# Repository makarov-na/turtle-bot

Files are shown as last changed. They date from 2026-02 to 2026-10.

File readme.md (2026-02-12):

## Реализация по мотивам проекта [TurtleBot3 Burger](https://www.turtlebot.com/) 

### Project goal: bot implementation on commodity hardware

The project uses widely available and cheaper components. 
Created custom waffle 3D models for printing at home with the ability to adapt to various 
components. Source files in FreeCAD format are available.

### Цель проекта: реализация бота с использованием более доступного железа

В проекте используются широко доступные и более дешевые компоненты. 
Реализованы модели для 3D печати в домашних условиях с возможностью адаптации 
под различные компоненты. Для всех деталей доступны исходники в 
формате FreeCAD.

[Ход проекта на YouTube](https://www.youtube.com/playlist?list=PLKxQTQ3TZlLEd_6ZOf-SUxFQ7dUuGvq06)




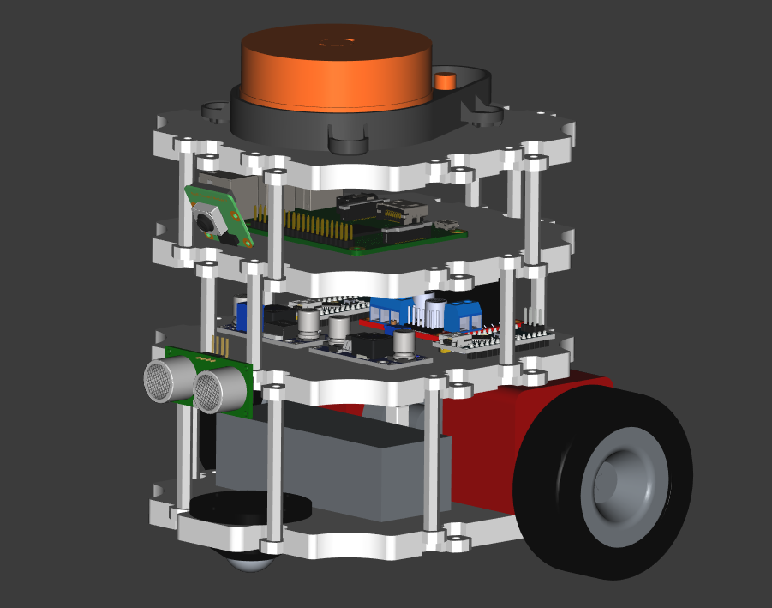
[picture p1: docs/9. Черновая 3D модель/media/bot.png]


1. [Компонентная архитектура](docs/1.%20%D0%9A%D0%BE%D0%BC%D0%BF%D0%BE%D0%BD%D0%B5%D0%BD%D1%82%D0%BD%D0%B0%D1%8F%20%D0%B0%D1%80%D1%85%D0%B8%D1%82%D0%B5%D0%BA%D1%82%D1%83%D1%80%D0%B0/%D0%9A%D0%BE%D0%BC%D0%BF%D0%BE%D0%BD%D0%B5%D0%BD%D1%82%D0%BD%D0%B0%D1%8F%20%D0%B0%D1%80%D1%85%D0%B8%D1%82%D0%B5%D0%BA%D1%82%D1%83%D1%80%D0%B0.md)
1. [Шасси](docs/2.%20%D0%A8%D0%B0%D1%81%D1%81%D0%B8/%D0%A8%D0%B0%D1%81%D1%81%D0%B8.md)
1. [Схема питания](docs/3.%20%D0%A1%D1%85%D0%B5%D0%BC%D0%B0%20%D0%BF%D0%B8%D1%82%D0%B0%D0%BD%D0%B8%D1%8F/%D0%A1%D1%85%D0%B5%D0%BC%D0%B0%20%D0%BF%D0%B8%D1%82%D0%B0%D0%BD%D0%B8%D1%8F.md)
1. [Черновая 3D модель](docs/9.%20%D0%A7%D0%B5%D1%80%D0%BD%D0%BE%D0%B2%D0%B0%D1%8F%203D%20%D0%BC%D0%BE%D0%B4%D0%B5%D0%BB%D1%8C/%D0%A7%D0%B5%D1%80%D0%BD%D0%BE%D0%B2%D0%B0%D1%8F%203D%20%D0%BC%D0%BE%D0%B4%D0%B5%D0%BB%D1%8C.md)
1. [Список компонентов](docs/%D0%A1%D0%BF%D0%B8%D1%81%D0%BE%D0%BA%20%D0%BA%D0%BE%D0%BC%D0%BF%D0%BE%D0%BD%D0%B5%D0%BD%D1%82%D0%BE%D0%B2/%D0%A1%D0%BF%D0%B8%D1%81%D0%BE%D0%BA%20%D0%BA%D0%BE%D0%BC%D0%BF%D0%BE%D0%BD%D0%B5%D0%BD%D1%82%D0%BE%D0%B2.md)
1. [3D модели (FreeCAD)](https://github.com/makarov-na/turtle-bot-3d-models)



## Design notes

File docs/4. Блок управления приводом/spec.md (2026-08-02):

# Описание доработки

## Функции модуля моторов:

* Отключение моторов
* Остановка моторов (силовое торможение)
* Установить линейную скорость в точке середины оси колёс
* Установить угловую скорость в точке середины оси колёс

## Настройки:

* Диаметр колёс, мм
* Колёсная база, мм
* Максимальная скорость, мм/с 

# Техничские детали:

## Программа:

* Нужно сделать скетч для ардуино.
* Функции реализовать в методах stop, power_stop, set_speed(linear_speed, angular_speed)
* Для проверки в главном цикле сделать вызов set_speed(0, 0) и отключить через 10 секунд вызовом stop()

## Модуль моторов состоит из:

* arduino nano
* драйвер моторов L298N Stepper DC Motor Driver
* моторы с энкодерами

## Подключение 

Подключение правого мотора:
* D2-IN1
* D3-IN2
* D5-ENA
* D8,D9 - энкодер (D8-A, D9-B)

Подключение левого мотора:
* D4-IN3
* D7-IN4
* D6-ENB
* D10,D11 - энкодер (D10-A, D11-B))

A - зелёный, B - жёлтый

Рабочий прототип реализован на arduino nano src/motor_controller/motor_controller/motor_controller.ino
Ничего из прототипа переносить не нужно. Нужно использовать для уточнений по подключению и направлениям моторов.

opencode -s ses_0411ac1bdffeHer3b0Qv4bnJya

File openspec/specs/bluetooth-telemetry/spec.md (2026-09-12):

# Bluetooth Telemetry

## Purpose
Передача отладочной телеметрии с Arduino на PC через HC-06 Bluetooth модуль по каналу Hardware Serial (D0/D1) с защитой логических уровней для RX HC-06.

## Requirements

### Requirement: Arduino SHALL send a startup greeting via HC-06

The system SHALL send the text message "hello PC from ARDU" once when the Arduino finishes setup, through the HC-06 Bluetooth module over Hardware Serial on pins D0 (RX) and D1 (TX) at 9600 baud. No periodic repetition of the greeting SHALL occur; the only further outgoing traffic is the per-command acknowledgement (separate requirement below).

#### Scenario: Greeting sent on startup

- **WHEN** Arduino powers on and completes setup
- **THEN** the message "hello PC from ARDU" is sent once via Hardware Serial to HC-06

#### Scenario: No periodic repetition

- **WHEN** 1 second has elapsed since the startup greeting
- **THEN** no further greetings or autonomous debug messages are sent; per-command acknowledgements are sent only in response to incoming commands

#### Scenario: Hardware Serial configuration unchanged

- **WHEN** Arduino setup() is called
- **THEN** Serial is initialized at 9600 baud on D0/D1 for both greeting output and incoming command parsing

### Requirement: Arduino SHALL acknowledge each command frame

The system SHALL send an acknowledgement line `ack <n> <linear> <angular>` over Hardware Serial (D0/D1, 9600 baud) after successfully parsing each valid `set_speed` command, where `<n>` is a running counter of processed commands and `<linear>`/`<angular>` are the parsed speeds (mm/s and rad/s). Together with the PC heartbeat (one command every 200 ms), this acknowledgement keeps the RFCOMM link continuously bidirectional. This keepalive is required because an HC-06 link with one-directional traffic drops at ~5.2 s, while continuous bidirectional traffic is verified to survive ≥60 s (bt-echo-test L3).

#### Scenario: Command is acknowledged

- **WHEN** the line `set_speed 30.0 0.0` arrives over Hardware Serial
- **THEN** the system replies `ack <n> 30.0 0.0` (n = incremented counter)

#### Scenario: Keepalive cadence

- **WHEN** valid commands arrive every 200 ms
- **THEN** an acknowledgement is sent for each command, producing continuous bidirectional RFCOMM traffic

#### Scenario: Invalid line is not acknowledged

- **WHEN** a line that does not match `set_speed` arrives
- **THEN** no acknowledgement is sent and the command counter does not increment

### Requirement: Hardware Serial SHALL be initialized on D0/D1

The system SHALL use the built-in Hardware Serial (UART) on pins D0 (RX, receiving from HC-06 TXD) and D1 (TX, transmitting to HC-06 RXD) at 9600 baud. SoftwareSerial MUST NOT be used, because its PCINT aliasing conflicts with the encoder `ISR(PCINT1_vect)` on the ATmega328P.

#### Scenario: Hardware Serial configuration

- **WHEN** Arduino setup() is called
- **THEN** Serial is initialized at 9600 baud

#### Scenario: HC-06 communication channel is independent from USB

- **WHEN** Hardware Serial is active on D0/D1
- **THEN** the same data is available both on HC-06 and on the USB/CH340 monitor

#### Scenario: No interrupt conflict with encoders

- **WHEN** the firmware is compiled with encoder ISR on PCINT1 and Hardware Serial
- **THEN** linking succeeds without a multiple definition error for the shared interrupt vector

### Requirement: Logic level conversion SHALL protect HC-06 RX

The system SHALL protect HC-06 RXD from Arduino 5V logic by using a voltage divider (5V → 3.3V) on the D1 (TX) to HC-06 RXD line. HC-06 TXD (3.3V) SHALL connect directly to D0 (RX), which reads 3.3V as a valid HIGH.

#### Scenario: Arduino TX to HC-06 RX

- **WHEN** Arduino transmits via D1 (TX, 5V)
- **THEN** the voltage divider drops the signal to 3.3V before reaching HC-06 RXD

#### Scenario: HC-06 TX to Arduino RX

- **WHEN** HC-06 transmits via TXD (3.3V)
- **THEN** the signal connects directly to Arduino D0 (RX) and is read as valid HIGH

### Requirement: HC-06 SHALL be powered from separate 5V source

The system SHALL power HC-06 VCC from the Cedar DC-DC buck converter 5V output, not from Arduino's 5V pin.

#### Scenario: HC-06 power supply

- **WHEN** Arduino is powered on
- **THEN** HC-06 receives 5V from Cedar buck converter via separate power wire

#### Scenario: Common ground

- **WHEN** HC-06 is powered from Cedar buck converter
- **THEN** HC-06 GND is connected to Arduino GND (common ground reference)

### Requirement: Existing motor control SHALL remain unchanged

The system SHALL preserve all existing motor control functionality (L298N, encoders, PID) without modification.

#### Scenario: Motor operation after HC-06 addition

- **WHEN** HC-06 is connected and transmitting
- **THEN** both motors respond to set_speed(), stop(), and power_stop() commands identically to before

#### Scenario: Encoder readings unaffected

- **WHEN** HC-06 is active on D0/D1 via Hardware Serial
- **THEN** encoder tick counts on A0-A3 continue to be read accurately, with no interrupt conflict

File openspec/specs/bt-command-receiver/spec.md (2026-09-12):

# BT Command Receiver

## Purpose
Приём и исполнение текстовых команд `set_speed <lin> <ang>` через Bluetooth-канал Hardware Serial (D0/D1, 9600 бод) с телеметрией-keepalive, watchdog-остановкой и безопасным поведением при старте.

## Requirements

### Requirement: Parse set_speed commands over Hardware Serial

The firmware SHALL read incoming lines from the Bluetooth channel via Hardware Serial (D0/D1, 9600 baud) and parse commands in the text form `set_speed <linear_speed> <angular_speed>`, where `linear_speed` is in mm/s and `angular_speed` in rad/s, both possibly negative floats. A valid command SHALL be applied through the existing `set_speed()` motion controller. Lines that do not match the syntax or that contain non-numeric values SHALL be ignored without affecting the current command.

#### Scenario: Valid command is applied

- **WHEN** the line `set_speed 90 0.65` arrives over Hardware Serial
- **THEN** the motion controller receives `set_speed(90, 0.65)` and the wheels respond accordingly

#### Scenario: Reverse command is applied

- **WHEN** the line `set_speed -60 0.0` arrives
- **THEN** the robot drives in reverse at 60 mm/s

#### Scenario: Command with turn is applied

- **WHEN** the line `set_speed 120 1.2` arrives
- **THEN** the robot drives forward while turning, per the differential drive model

#### Scenario: Zero-speed command actively brakes

- **WHEN** the line `set_speed 0.0 0.0` arrives while the robot is moving
- **THEN** the robot executes an active braking stop (power_stop) and resets the PID integral, so it does not keep drifting forward from accumulated integrator windup

#### Scenario: Malformed line is ignored

- **WHEN** a line such as `set_speed abc def` or `stop_now` arrives
- **THEN** the line is ignored and the current command remains active

#### Scenario: Line terminator handling

- **WHEN** the parser receives a complete command terminated by a newline
- **THEN** the command is processed exactly once, and partial fragments are buffered until the newline

### Requirement: Watchdog stop on command timeout

The firmware SHALL stop the robot if no valid command is received within a timeout window, so a lost Bluetooth connection or a crashed host application does not leave the robot moving indefinitely. Each valid received command SHALL reset the watchdog timer. When the timeout expires with no new command, the firmware SHALL execute `stop()` and remain stopped until the next valid command.

#### Scenario: Commands keep arriving

- **WHEN** valid commands arrive at least once per timeout window
- **THEN** the robot continues to follow the latest command without stopping

#### Scenario: Link drops during motion

- **WHEN** the last command set a non-zero speed and then no further data arrives for the timeout duration
- **THEN** the robot stops with `stop()` and does not resume motoring until a new valid command arrives

#### Scenario: Link drops while stopped

- **WHEN** the robot is already stopped at `set_speed(0, 0)` and no data arrives
- **THEN** the robot remains stopped

### Requirement: No autonomous motion on startup

The firmware SHALL NOT start any motion by itself. The demo sequence (automatic run at test speed followed by automatic stop) SHALL be removed. After boot the robot SHALL remain stopped until it receives a command from the host.

#### Scenario: Boot leaves robot stopped

- **WHEN** the Arduino boots and completes setup with no host connected
- **THEN** both wheels remain stopped and the robot does not move

#### Scenario: First command starts motion

- **WHEN** the first valid `set_speed` command arrives after boot
- **THEN** the robot moves according to that command only

#### Scenario: Startup greeting sent once

- **WHEN** the Arduino completes setup
- **THEN** a single greeting message is sent over Hardware Serial, and no further periodic messages are sent

### Requirement: Out-of-range commands are handled safely

The firmware SHALL accept commands whose values exceed the configured limits and SHALL handle them through the existing speed limiting so that no wheel is driven beyond `V_MAX_MM_S`. The command SHALL NOT be rejected or disrupt the control loop.

#### Scenario: Command above maximum speed

- **WHEN** `set_speed 500 0` arrives with `V_MAX_MM_S = 300`
- **THEN** the motion controller clamps the wheel targets within the limit via the curvature-preserving clipping rule

#### Scenario: Command with excessive rotation

- **WHEN** `set_speed 0 10` arrives with `ω_max ≈ 3.24` rad/s
- **THEN** the motion controller scales the wheel targets down and the robot spins at a rate within the limit

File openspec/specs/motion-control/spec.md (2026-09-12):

# Motion Control

## Purpose
Define the body-frame velocity command surface, differential drive kinematics, speed limiting, acceleration ramping, and closed-loop per-wheel speed control for the robot's motor controller firmware.

## Requirements

### Requirement: Set body-frame velocity
The motion controller SHALL provide a `set_speed(linear_speed, angular_speed)` command where `linear_speed` is the linear velocity of the midpoint of the wheel axis in mm/s and `angular_speed` is the angular velocity in rad/s. Positive angular velocity SHALL mean counter-clockwise rotation viewed from above; negative SHALL mean clockwise. The controller SHALL translate a positive linear command into forward motion of the robot, accounting for the physical mounting orientation of each motor.

#### Scenario: Forward motion
- **WHEN** `set_speed(100, 0)` is issued
- **THEN** both wheels rotate such that the robot moves forward at 100 mm/s

#### Scenario: In-place counter-clockwise turn
- **WHEN** `set_speed(0, 1.0)` is issued
- **THEN** the wheels rotate in opposite directions producing a counter-clockwise spin about the midpoint of the wheel axis

#### Scenario: In-place clockwise turn
- **WHEN** `set_speed(0, -1.0)` is issued
- **THEN** the wheels rotate in opposite directions producing a clockwise spin

### Requirement: Differential drive kinematics
The controller SHALL compute per-wheel target linear speeds from the body-frame command using the differential drive model `v_l = v - ω·B/2` and `v_r = v + ω·B/2`, where `B` is the configured wheelbase.

#### Scenario: Forward with slight turn
- **WHEN** a command `(v, ω)` produces wheel targets where one wheel is faster than the other
- **THEN** the computed targets reflect the turn: one wheel faster, the other slower, with the difference proportional to `ω·B`

### Requirement: Curvature-preserving clipping
When a command would drive either wheel beyond the configured maximum speed, the controller SHALL scale **both** wheel targets by the same factor `k = v_max / max(|v_l|, |v_r|)` so the curvature of the commanded trajectory is preserved. When neither wheel target exceeds the maximum, the targets SHALL be used unchanged.

#### Scenario: Command within limits
- **WHEN** a command yields both wheel targets at or below `v_max`
- **THEN** the targets are applied unchanged

#### Scenario: One wheel exceeds the maximum
- **WHEN** a command yields `|v_r| = 300` mm/s with `v_max = 200` mm/s and `|v_l| = 100` mm/s
- **THEN** both targets are scaled by `k = 2/3` to `200` mm/s and `66.7` mm/s, preserving their ratio

#### Scenario: Pure rotation at the limit
- **WHEN** `set_speed(0, ω)` is issued such that `|ω|·B/2` exceeds `v_max`
- **THEN** the wheel targets are scaled down so the robot spins about the same center at a lower rate

### Requirement: Smooth acceleration
The controller SHALL ramp wheel speed from the current value to the commanded target over a configured ramp duration instead of stepping instantly. The ramp SHALL apply to both wheels.

#### Scenario: Ramp from rest
- **WHEN** `set_speed(200, 0)` is issued while the wheels are at rest
- **THEN** wheel speed increases gradually toward 200 mm/s without an instantaneous step

#### Scenario: Ramp on target change
- **WHEN** a new command changes the target while a ramp is in progress
- **THEN** the wheels transition smoothly from the current speed to the new target

### Requirement: Closed-loop wheel speed control
The controller SHALL measure real wheel rotation speed using the motor encoders and SHALL adjust the PWM output via a PID controller so each wheel tracks its commanded target speed. The feedback SHALL be sign-correct: a wheel spun forward by an external force SHALL be opposed (braked) by the loop, not driven further. The controller SHALL include a static feedforward term from the commanded speed to PWM so the loop can reach low-speed targets even when the mechanical free-play threshold (stiction/cogging) is above what the error-driven terms alone can produce. After any pause during which the control loop did not run (braking, coasting, watchdog stop), the first iteration SHALL NOT attribute the accumulated encoder delta or elapsed wall time to the current control step, so resuming motion causes no false speed reading or integrator spike.

#### Scenario: Tracks the commanded speed
- **WHEN** a target wheel speed is set
- **THEN** the measured wheel speed converges to the target within the configured tolerance

#### Scenario: Recovers from load disturbance
- **WHEN** a momentary load slows a wheel below its target
- **THEN** the PID controller increases output to restore the wheel to the target speed

#### Scenario: Hand-spun wheel is braked (sign check)
- **WHEN** a wheel is spun forward by hand while the loop is active at a low or zero target
- **THEN** the measured speed of that wheel is positive and the PWM output goes opposite to the spin (the motor resists the hand rotation)

#### Scenario: Low-speed target is reachable
- **WHEN** the commanded target is below the mechanical free-play threshold of the drivetrain
- **THEN** the feedforward plus accumulated integrator raise the PWM output enough to start the wheel within a bounded time

#### Scenario: Resume after a stop is clean
- **WHEN** a non-zero command resumes the loop after a pause longer than one control period with no loop activity
- **THEN** the first control steps use a nominal step time (not the whole pause duration) and treat the encoder delta since the pause as zero, so no integrator whiplash or false speed spike occurs

### Requirement: Configurable parameters
The controller SHALL support configuration of wheel diameter (mm), wheelbase (mm), and maximum linear speed (mm/s). Maximum angular velocity SHALL be derived as `ω_max = 2·v_max / B` and SHALL NOT require separate configuration. Commands producing wheel targets beyond the limits SHALL be handled by the curvature-preserving clipping rule.

#### Scenario: Wheel diameter affects speed mapping
- **WHEN** the configured wheel diameter is changed
- **THEN** the wheel rotation speed required for the same body linear speed changes inversely with the diameter

#### Scenario: Derived maximum angular velocity
- **WHEN** wheelbase `B` and maximum speed `v_max` are configured
- **THEN** the maximum angular velocity is `2·v_max/B` without separate configuration

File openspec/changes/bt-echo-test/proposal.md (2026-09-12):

## Why

Канал управления ботом через HC-06 внедрён (change `bt-keyboard-control`), но при проверке на железе связь оказалась
нестабильной: RFCOMM-линк падает раз в ~5 с. Прямая команда `set_speed` через `echo > /dev/rfcomm0` реакции не дала.
Нужно изолировать Bluetooth-канал (ПК ↔ HC-06 ↔ Nano) от моторов и watchdog и проверить его отдельным тестовым скетчем,
заодно эмпирически оценив поведение линка при непрерывном двунаправленном трафике.

## What Changes

- **BREAKING**: нет. Боевой `motor_controller.ino` не трогается.
- Добавляется отдельный тестовый скетч `src/motor_controller/bt_echo_test/bt_echo_test.ino`, который принимает текстовые
  строки с ПК через Hardware Serial (D0/D1 → HC-06, 9600 бод) и возвращает их обратно с нарастающим счётчиком (
  `echo <n>: <line>`). Моторы (L298N) не задействуются, watchdog отсутствует — бот отвечает всегда, даже когда ПК
  молчит.
- Однократное приветствие в `setup()` через тот же канал.
- Описывается способ проверки консольными командами Linux: привязка rfcomm, отключение локального терминального эха (
  `stty raw -echo`), ручной эхо-тест, цикл замера RTT и длинный тест на устойчивость линка.

## Capabilities

### New Capabilities

- `bt-echo-test`: отдельный тестовый скетч приёма/отправки текста через HC-06 с счётчиком эха и консольная инструкция
  проверки канала через Linux.

### Modified Capabilities

<!-- нет изменяемых существующих способностей -->

## Impact

- Новый файл `src/motor_controller/bt_echo_test/bt_echo_test.ino` — отдельно компилируемый скетч (по образцу
  `encoder_test/encoder_test.ino`).
- Код проверки на стороне ПК (bash/python stdlib) приводится в spec/design, отдельного приложения не создаётся.
- Канал используется по существующим ограничениям `bluetooth-telemetry`: Hardware Serial D0/D1, 9600 бод, питание HC-06
  от отдельного 5V (Cedar buck).

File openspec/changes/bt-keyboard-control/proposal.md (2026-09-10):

## Why

Робот теперь имеет Bluetooth-канал (HC-06) и готовый контур управления `set_speed(linear, angular)`, но управлять им с ПК пока нельзя: скетч работает в демо-режиме (автозапуск на 250 мм/с на 9 секунд), а канал используется только для отладочных сообщений. Нужна базовая консольная система управления как первый шаг к дистанционному телеуправлению.

## What Changes

- **BREAKING**: из `src/motor_controller/motor_controller/motor_controller.ino` убирается демо-режим (`set_speed(TEST_SPEED_MM_S, 0)` + `power_stop()` через `TEST_RUN_TIME_MS`) и периодическая отправка «hello PC from ARDU». При старте выдаётся однократное приветствие вместо повтора раз в секунду.
- Arduino-скетч принимает текстовые команды `set_speed <linear> <angular>\n` через Hardware Serial (HC-06, 9600 бод) и применяет их через существующий контур управления.
- Добавляется watchdog: если команды не поступали более 1 секунды, бот выполняет `stop()` (аварийная остановка при обрыве Bluetooth или падении приложения).
- В папке со скетчем создаётся Python-приложение `controller.py` (консольное): работает в raw-режиме терминала, читает стрелки без Enter.
- Модель управления — дискретные инкременты: при старте отправляется `set_speed(0, 0)`, каждое нажатие стрелки меняет удерживаемую скорость на ±10% от максимума; бот держит последнюю команду до следующего нажатия.
- Линейная скорость меняется стрелками Up/Down (задний ход — в минус), угловая — Left/Right (симметрично в обе стороны); движение вперёд и поворот комбинируются в одной команде `set_speed`.
- ПК повторяет текущую команду каждые 200 мс (одновременно heartbeat для watchdog).
- При выходе из приложения (Ctrl+C или `q`) отправляется `set_speed(0, 0)`.

## Capabilities

### New Capabilities

- `bt-command-receiver`: приём и разбор текстовых команд `set_speed` в прошивке Arduino через Hardware Serial, нормализация/ограничение скоростей, watchdog-остановка при пропадании потока команд.
- `pc-keyboard-control`: консольное Python-приложение с управлением стрелками, дискретными инкрементами ±10%, повторением команды и корректным завершением.

### Modified Capabilities

- `bluetooth-telemetry`: требование «периодическая отправка "hello PC from ARDU" раз в секунду» заменяется на однократное приветствие при старте. Канал остаётся на Hardware Serial D0/D1, 9600 бод.

## Impact

- `src/motor_controller/motor_controller/motor_controller.ino` — удаление демо-кода, добавление парсинга команд из Serial и watchdog-таймера.
- Новый файл `src/motor_controller/motor_controller/controller.py` — консольный контроллер на Python (stdlib, без сторонних зависимостей).
- Лимиты скоростей (`V_MAX_MM_S = 300`, `OMEGA_MAX_RAD_S = 2·V_MAX/WHEELBASE`) дублируются константами в controller.py — совпадение с прошивкой поддерживается вручную.
- HC-06: Bluetooth-соединение с ПК выглядит как последовательный порт (`/dev/rfcomm0` или аналогичный), адрес передаётся аргументом запуска.

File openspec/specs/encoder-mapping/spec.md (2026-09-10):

# Encoder Mapping

## Purpose
Define the mapping between motor encoders and wheel PID feedback channels, the per-wheel direction sign convention, and the wiring documentation so the robot drives straight and predictable.

## Requirements

### Requirement: Correct encoder-to-wheel mapping
The controller SHALL associate each wheel's PID feedback channel with the encoder physically attached to that same wheel. The left wheel SHALL read the encoder connected to pins A2/A3 and the right wheel SHALL read the encoder connected to pins A0/A1, matching the physical wiring.

#### Scenario: Left wheel feedback reads left encoder
- **WHEN** the left wheel's motor rotates and the right wheel's motor is stationary
- **THEN** the left wheel's measured speed reflects the left wheel's own encoder tick count and the right wheel's measured speed is zero

#### Scenario: Right wheel feedback reads right encoder
- **WHEN** the right wheel's motor rotates and the left wheel's motor is stationary
- **THEN** the right wheel's measured speed reflects the right wheel's own encoder tick count and the left wheel's measured speed is zero

#### Scenario: Straight forward motion
- **WHEN** `set_speed(250, 0)` is issued with the correct mapping in place
- **THEN** both wheels track their own commanded speed without the PID chasing the other wheel, and the robot does not turn sharply

### Requirement: Encoder direction sign per wheel
Each wheel's measured speed SHALL be positive when the wheel drives the robot forward, accounting for the mirror-mounted left motor. The firmware SHALL expose per-wheel sign compensation so a mismatched encoder channel polarity can be corrected without rewiring.

#### Scenario: Forward rotation reads positive on both wheels
- **WHEN** the robot is commanded forward and both wheels rotate in the direction that moves the robot forward
- **THEN** both wheels' measured speeds are positive

#### Scenario: Backward rotation reads negative on both wheels
- **WHEN** the robot is commanded backward and both wheels rotate in the direction that moves the robot backward
- **THEN** both wheels' measured speeds are negative

#### Scenario: Sign correction without rewiring
- **WHEN** an encoder channel polarity mismatch causes a wheel to measure its direction inverted
- **THEN** the wheel's sign compensation can be flipped in firmware and the wheel then reads the correct direction

### Requirement: Consistent wiring documentation
The wiring reference SHALL state the encoder connections that match the physical hardware: left motor encoder on A2/A3 and right motor encoder on A0/A1, consistent with the firmware mapping.

#### Scenario: Documentation matches hardware
- **WHEN** an operator rebuilds the wiring from the reference document
- **THEN** the encoder connections match the firmware mapping and the physical hardware

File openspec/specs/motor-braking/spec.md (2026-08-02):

# Motor Braking

## Purpose
Define the safe default state of the motor driver after reset and the behavior of the `stop()` and `power_stop()` commands, so the robot never self-drives on boot and braking is explicit and bounded.

## Requirements

### Requirement: Motors disabled after reset
On startup the controller SHALL leave the motors disabled so that no drive voltage is applied until a command is issued.

#### Scenario: Boot with motors off
- **WHEN** the controller boots
- **THEN** the motors remain off and the wheels can be turned by hand

### Requirement: stop() disables motors
`stop()` SHALL disable the motor driver so that the wheels coast freely with no braking force applied.

#### Scenario: Free coast
- **WHEN** `stop()` is called while the robot is stationary
- **THEN** the driver output is disabled and the wheels are free to spin

### Requirement: power_stop() applies dynamic braking
`power_stop()` SHALL apply the L298N fast motor stop (both IN inputs driven high while the enable is active) for the configured brake duration, then release to the disabled state.

#### Scenario: Brake then release
- **WHEN** `power_stop()` is called
- **THEN** both motors are actively braked for the configured brake duration and then released to the disabled state

#### Scenario: Brake duration is bounded
- **WHEN** `power_stop()` is called repeatedly
- **THEN** each call performs the same bounded brake sequence and never leaves the driver in a persistent braking state

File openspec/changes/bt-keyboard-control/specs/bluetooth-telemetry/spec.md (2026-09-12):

## REMOVED Requirements

### Requirement: Arduino SHALL send periodic debug messages via HC-06

**Reason**: Периодическое сообщение «hello PC from ARDU» было тестовым. Канал теперь используется для приёма команд управления от ПК, а не только для телеметрии наружу.

**Migration**: Диагностика подключения выполняется по однократному приветствию при старте, которое выводит бот через тот же канал. Периодическая отправка не требуется.

## ADDED Requirements

### Requirement: Arduino SHALL send a startup greeting via HC-06

The system SHALL send the text message "hello PC from ARDU" once when the Arduino finishes setup, through the HC-06 Bluetooth module over Hardware Serial on pins D0 (RX) and D1 (TX) at 9600 baud. No periodic repetition of the greeting SHALL occur; the only further outgoing traffic is the per-command acknowledgement (separate requirement below).

#### Scenario: Greeting sent on startup

- **WHEN** Arduino powers on and completes setup
- **THEN** the message "hello PC from ARDU" is sent once via Hardware Serial to HC-06

#### Scenario: No periodic repetition

- **WHEN** 1 second has elapsed since the startup greeting
- **THEN** no further greetings or autonomous debug messages are sent; per-command acknowledgements are sent only in response to incoming commands

#### Scenario: Hardware Serial configuration unchanged

- **WHEN** Arduino setup() is called
- **THEN** Serial is initialized at 9600 baud on D0/D1 for both greeting output and incoming command parsing

### Requirement: Arduino SHALL acknowledge each command frame

The system SHALL send an acknowledgement line `ack <n> <linear> <angular>` over Hardware Serial (D0/D1, 9600 baud) after successfully parsing each valid `set_speed` command, where `<n>` is a running counter of processed commands and `<linear>`/`<angular>` are the parsed speeds (mm/s and rad/s). Together with the PC heartbeat (one command every 200 ms), this acknowledgement keeps the RFCOMM link continuously bidirectional. This keepalive is required because an HC-06 link with one-directional traffic drops at ~5.2 s, while continuous bidirectional traffic is verified to survive ≥60 s (bt-echo-test L3).

#### Scenario: Command is acknowledged

- **WHEN** the line `set_speed 30.0 0.0` arrives over Hardware Serial
- **THEN** the system replies `ack <n> 30.0 0.0` (n = incremented counter)

#### Scenario: Keepalive cadence

- **WHEN** valid commands arrive every 200 ms
- **THEN** an acknowledgement is sent for each command, producing continuous bidirectional RFCOMM traffic

#### Scenario: Invalid line is not acknowledged

- **WHEN** a line that does not match `set_speed` arrives
- **THEN** no acknowledgement is sent and the command counter does not increment

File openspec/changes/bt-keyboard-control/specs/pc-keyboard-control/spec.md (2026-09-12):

## ADDED Requirements

### Requirement: Console app reads arrow keys without Enter

The application SHALL run a console (terminal) session in raw mode and SHALL recognize the arrow keys Up, Down, Left, Right, and the exit key `q`, reacting to a key press immediately without requiring the Enter key. Terminal contents and behavior SHALL be restored when the application exits.

#### Scenario: Arrow key press is detected immediately

- **WHEN** the user presses an arrow key while the application runs
- **THEN** the application reacts to that key press without waiting for Enter

#### Scenario: Exit key recognized

- **WHEN** the user presses `q` or sends Ctrl+C
- **THEN** the application shuts down and restores the terminal

### Requirement: Discrete speed increments

Starting from `set_speed(0, 0)`, each arrow key press SHALL change the held command by exactly 10% of the configured maximum: Up increments linear speed, Down decrements linear speed, Left increments angular speed, Right decrements angular speed. Linear and angular components SHALL be maintained independently (a forward-and-turn command keeps both components). Each component SHALL be capped so it never exceeds ±100% of its maximum, and Down beyond 0% SHALL continue into negative linear speed (reverse driving).

#### Scenario: Initial command is zero

- **WHEN** the application starts and connects
- **THEN** it sends `set_speed 0.0 0.0` as the initial command

#### Scenario: Linear increment

- **WHEN** the user presses Up once
- **THEN** the linear component becomes +10% of maximum and is sent as the new command

#### Scenario: Linear decrement into reverse

- **WHEN** the user presses Down while linear speed is at +10%
- **THEN** the linear component returns to 0%, and a further Down press drives into negative (reverse) territory

#### Scenario: Angular increment and decrement

- **WHEN** the user presses Left and then Right
- **THEN** the angular component first rises to +10% and then returns to 0% of the angular maximum

#### Scenario: Combined forward and turn

- **WHEN** the user presses Up followed by Left
- **THEN** the command keeps the linear increment and adds the angular increment, resulting in a turn while driving forward

#### Scenario: Cap at maximum

- **WHEN** the user presses Up ten times from zero
- **THEN** the linear component reaches +100% and additional Up presses do not raise it further

### Requirement: Command mapping matches firmware limits

The application SHALL treat +100% linear speed as `V_MAX_MM_S = 300` mm/s and +100% angular speed as `ω_max = 2·300/WHEELBASE_MM ≈ 3.24` rad/s, matching the constants defined in the firmware, and SHALL send numeric values to one decimal place for mm/s and two decimal places for rad/s.

#### Scenario: Ten percent step maps to firmware units

- **WHEN** the user presses Up once
- **THEN** the application sends `set_speed 30.0 0.0` (10% of 300 mm/s)

#### Scenario: Angular step maps to firmware units

- **WHEN** the user presses Left once
- **THEN** the application sends an angular value of approximately 0.32 rad/s (10% of ω_max)

### Requirement: Command repetition as heartbeat

While connected and running, the application SHALL resend the current command at a fixed interval of 200 ms, so the firmware watchdog (which stops the robot after a timeout) is reset, and so a host link drop is automatically detected on the firmware side.

#### Scenario: Steady heartbeat while idle

- **WHEN** the command is unchanged and the application is running
- **THEN** the current command is resent every 200 ms

#### Scenario: Heartbeat tone on each change

- **WHEN** the user changes the command with an arrow key
- **THEN** the new command is sent immediately and continues to be repeated every 200 ms

### Requirement: Graceful shutdown stops the robot

When the application exits, whether via `q`, Ctrl+C, or the reconnection attempts after a link loss being exhausted, it SHALL send a final `set_speed 0.0 0.0` before closing the connection so the robot does not continue moving with the last non-zero command.

#### Scenario: Quit via key sends stop

- **WHEN** the user presses `q`
- **THEN** the application sends `set_speed 0.0 0.0` and then closes the serial port

#### Scenario: Exit via Ctrl+C sends stop

- **WHEN** the user interrupts the application with Ctrl+C
- **THEN** the application sends `set_speed 0.0 0.0` and restores the terminal

#### Scenario: Exit after failed reconnect sends stop

- **WHEN** a link loss cannot be repaired within the reconnection attempts
- **THEN** the application sends `set_speed 0.0 0.0` and exits with an error message

### Requirement: Auto-reconnect on lost link

While running, if the connection to the robot is lost (for example a Bluetooth RFCOMM link that drops), the application SHALL automatically reconnect to the same port and resume sending the current command, keeping the current linear and angular components. It SHALL repeat the reconnection at most 5 times with a 0.5 s pause between attempts; if all attempts fail, the application SHALL exit per the graceful-shutdown requirement. A link loss SHALL not reset the user's held command.

#### Scenario: Link drop while driving resumes

- **WHEN** the connection drops while a non-zero command is held
- **THEN** the application reconnects and continues sending the same command without the user having to rebuild it from zero

#### Scenario: Unrecoverable link loss exits cleanly

- **WHEN** reconnection attempts all fail
- **THEN** the application prints a readable error message and exits with a final stop command

### Requirement: Incoming telemetry is drained while running

While connected, the application SHALL continuously read and discard incoming bytes from the serial port (the bot's keepalive acknowledgements). This keeps the terminal input buffer from filling up, which would otherwise stall the RFCOMM flow control and break the channel over time.

#### Scenario: Acknowledgements are drained

- **WHEN** the bot sends `ack ...` lines every ~200 ms while the application is connected
- **THEN** the application reads them promptly so the input buffer does not grow without bound

#### Scenario: Link closure mid-run is detected via read errors

- **WHEN** the channel closes while driving and a read or write on the port raises an I/O error (for example `EIO` on a dropped RFCOMM link)
- **THEN** the application treats it as a link loss and enters the auto-reconnect flow; an empty read on an idle tty (a no-op return with no data, which is normal on a `VMIN=0` port) is ignored and does not count as a closure

### Requirement: Serial port is supplied as a launch argument

The application SHALL accept the serial port device as its single command-line argument (for example `/dev/rfcomm0`) and SHALL connect at 9600 baud. If the port is missing or cannot be opened, the application SHALL print a clear error and exit.

#### Scenario: Port provided and opened

- **WHEN** the application is launched with a valid device path
- **THEN** it connects to the device at 9600 baud and starts sending commands

#### Scenario: Port missing

- **WHEN** the application is launched with no argument
- **THEN** it prints usage information and exits without an error trace

#### Scenario: Port cannot be opened

- **WHEN** the device path is invalid or the device is in use
- **THEN** the application prints a readable error message and exits

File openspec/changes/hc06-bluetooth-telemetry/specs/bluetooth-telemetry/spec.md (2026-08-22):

## ADDED Requirements

### Requirement: Arduino SHALL send periodic debug messages via HC-06
The system SHALL send the text message "hello PC from ARDU" through HC-06 Bluetooth module every 1 second using SoftwareSerial on pins D12 (RX) and D13 (TX).

#### Scenario: Message sent on startup
- **WHEN** Arduino powers on and completes setup
- **THEN** the message "hello PC from ARDU" is sent via SoftwareSerial to HC-06

#### Scenario: Periodic repetition
- **WHEN** 1 second has elapsed since the last message was sent
- **THEN** the message "hello PC from ARDU" is sent again via SoftwareSerial to HC-06

#### Scenario: Continuous operation
- **WHEN** Arduino is running and HC-06 is connected
- **THEN** messages continue to be sent every 1 second without stopping

### Requirement: SoftwareSerial SHALL be initialized on D12/D13
The system SHALL use SoftwareSerial library with pin D12 as RX (receiving from HC-06 TXD) and pin D13 as TX (transmitting to HC-06 RXD) at 9600 baud.

#### Scenario: SoftwareSerial configuration
- **WHEN** Arduino setup() is called
- **THEN** SoftwareSerial is initialized with RX=D12, TX=D13 at 9600 baud

#### Scenario: HC-06 communication channel is independent from USB
- **WHEN** SoftwareSerial is active on D12/D13
- **THEN** Hardware Serial (D0/D1) remains available for USB/CH340 communication

### Requirement: Level shifter SHALL convert logic levels between Arduino and HC-06
The system SHALL use a BSS138-based level shifter module to convert 5V logic from Arduino to 3.3V logic for HC-06 RXD, and 3.3V logic from HC-06 TXD to 5V for Arduino D12.

#### Scenario: Arduino TX to HC-06 RX
- **WHEN** Arduino transmits via SoftwareSerial TX (D13, 5V)
- **THEN** the level shifter converts the signal to 3.3V before reaching HC-06 RXD

#### Scenario: HC-06 TX to Arduino RX
- **WHEN** HC-06 transmits via TXD (3.3V)
- **THEN** the level shifter converts the signal to 5V before reaching Arduino D12

### Requirement: HC-06 SHALL be powered from separate 5V source
The system SHALL power HC-06 VCC from the Cedar DC-DC buck converter 5V output, not from Arduino's 5V pin.

#### Scenario: HC-06 power supply
- **WHEN** Arduino is powered on
- **THEN** HC-06 receives 5V from Cedar buck converter via separate power wire

#### Scenario: Common ground
- **WHEN** HC-06 is powered from Cedar buck converter
- **THEN** HC-06 GND is connected to Arduino GND (common ground reference)

### Requirement: Existing motor control SHALL remain unchanged
The system SHALL preserve all existing motor control functionality (L298N, encoders, PID) without modification.

#### Scenario: Motor operation after HC-06 addition
- **WHEN** HC-06 is connected and transmitting
- **THEN** both motors respond to set_speed(), stop(), and power_stop() commands identically to before

#### Scenario: Encoder readings unaffected
- **WHEN** HC-06 is active on D12/D13
- **THEN** encoder tick counts on D8-D11 are unaffected

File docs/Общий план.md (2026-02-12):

1. [Компонентная архитектура.md](1.%20%D0%9A%D0%BE%D0%BC%D0%BF%D0%BE%D0%BD%D0%B5%D0%BD%D1%82%D0%BD%D0%B0%D1%8F%20%D0%B0%D1%80%D1%85%D0%B8%D1%82%D0%B5%D0%BA%D1%82%D1%83%D1%80%D0%B0/%D0%9A%D0%BE%D0%BC%D0%BF%D0%BE%D0%BD%D0%B5%D0%BD%D1%82%D0%BD%D0%B0%D1%8F%20%D0%B0%D1%80%D1%85%D0%B8%D1%82%D0%B5%D0%BA%D1%82%D1%83%D1%80%D0%B0.md)
1. Схема питания (расчет потребления, выбор аккумулятора, 5V, 12V, силовая, общая)
1. 3D модель черновая
1. Блок управления приводом (компоненты, 3D модель чистовая с креплениями, аккумулятором, выключателем, электрическая схема, реализация и демо базовых функций)
1. Интеграция главного блока с блоком приводов (протокол, реализация на двух сторонах)

### Шаги

* Описать какая информация передается и какие функции у компонентов

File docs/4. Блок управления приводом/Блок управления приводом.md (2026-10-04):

## API

| КОМАНДА | ОПИСАНИЕ |
|---|---|
| `set_speed v ω` | Ехать: линейная скорость v (мм/с), угловая ω (рад/с, + = против часовой).<br>Внутри — кинематика и PID на каждое колесо |
| `stop` | Стоп: отключить драйвер, свободный выбег колёс |
| `power_stop` | Экстренное торможение: L298N fast stop, 300 мс, затем выбег |

## Управление через bluetooth 

Используемый модуль: HC-06

### Подключение электрическое

| Провод | Направление | Куда идёт |
|---|---|---|
| Arduino D13  | → | Level shifter HV1 |
| Arduino D12  | ← | Level shifter HV2 |
| Arduino 5V | → | Level shifter VCC_HV|
| Arduino 3.3V | → | Level shifter VCC_LV|
| Arduino GND  | → | Level shifter GND |
| Arduino GND  | → | HC-06 GND |
| Level LV1 | → | HC-06 RXD |
| Level LV2 | ← | HC-06 TXD |
| 5V (Cedar) | → | HC-06 VCC |
| GND (Cedar)  | → | HC-06 GND |

| PIN | ФУНКЦИЯ | НАПРАВЛ. | УСТРОЙСТВО |
|---|---|---|---|
| D12 | Serial RX (SW) | IN ◀ | HC-06 TXD (через level shifter)  |
| D13 | Serial TX (SW) | OUT ▶ | HC-06 RXD (через level shifter)  |
| D2 | Motor dir A (Right) | OUT ▶ | L298N IN1 |
| D3 | Motor dir B (Right) | OUT ▶ | L298N IN2 |
| D4 | Motor dir A (Left) | OUT ▶ | L298N IN3 |
| D5 | Motor speed (Right PWM)  | OUT ▶ | L298N ENA |
| D6 | Motor speed (Left PWM) | OUT ▶ | L298N ENB |
| D7 | Motor dir B (Left) | OUT ▶ | L298N IN4 |
| D8 | FREE | — | |
| D9 | FREE | — | |
| D10 | FREE | — | |
| D11 | FREE | — | |
| A0 | Encoder Right A | IN ◀ | JGB37-520 Right |
| A1 | Encoder Right B | IN ◀ | JGB37-520 Right |
| A2 | Encoder Left A | IN ◀ | JGB37-520 Left |
| A3 | Encoder Left B | IN ◀ | JGB37-520 Left |
| A4/A5 | I2C (SDA/SCL) | — | (не используется) |
| A6/A7 | FREE (ADC only) | — | |
| 5V | Питание level shifter HV | POWER | Level shifter |
| 3.3V  | Питание level shifter LV | POWER | Level shifter |
| GND | Общая земля | POWER | ВСЕ устройства |

При подключении к D0 и D1 не работает USB подключение. Надо уводить на другие пины

### Подключение на PC

```shell
bluetoothctl devices

Device 00:21:13:00:0C:E3 HC-06
```
PIN 1234
```shell
bluetoothctl pair 00:21:13:00:0C:E3
Attempting to pair with 00:21:13:00:0C:E3
[CHG] Device 00:21:13:00:0C:E3 Connected: yes
[CHG] Device 00:21:13:00:0C:E3 RSSI is nil
[CHG] Device 00:C3:F4:06:6A:F3 RSSI is nil
[CHG] Controller C4:85:08:AD:5A:56 Discovering: no
[CHG] Device 00:21:13:00:0C:E3 Bonded: yes
[CHG] Device 00:21:13:00:0C:E3 UUIDs: 00001101-0000-1000-8000-00805f9b34fb
[CHG] Device 00:21:13:00:0C:E3 ServicesResolved: yes
[CHG] Device 00:21:13:00:0C:E3 Paired: yes
Pairing successful
```
```shell
sudo rfcomm bind rfcomm0 00:21:13:00:0C:E3 1
```

Светодиод будет мигать часто до подключения к терминалу.

Не нужно использовать bluetoothctl connect - всегда будет ошибка

/dev/rfcomm0 — это виртуальный файл устройства в Linux, который представляет собой 
последовательный порт (UART), перенаправленный через Bluetooth.Когда вы привязываете модуль HC-06 командой rfcomm bind,
Linux создает этот файл в каталоге /dev/ (от слова devices). 

Для операционной системы и любых программ работа с HC-06
через этот файл выглядит абсолютно так же, как работа с обычной флешкой-программатором, COM-портом или USB-кабелем 
Arduino (/dev/ttyUSB0). Когда вы записываете данные в /dev/rfcomm0, Linux передает их по радиоканалу Bluetooth на HC-06. 
Когда Arduino отправляет данные в свой TX-пин, они летят по воздуху и появляются в файле /dev/rfcomm0.

```shell
cat /dev/rfcomm0

```
Или

```shell
picocom -b 9600 /dev/rfcomm0
```

После подключения светодиод перестает мигать часто и в консоли появляется сообщения.
Если просто выйти из консоли, то порт будет занят. Нужно убить процесс picocom.

```shell
sudo lsof /dev/rfcomm0

```

## Телеметрия

Бот отвечает на каждую команду `set_speed` строкой `ack` (раз в ~200 мс):

```
ack <n> <v> <w> mL=<mL> mR=<mR> oL=<oL> oR=<oR> iL=<iL> iR=<iR>
```

### Метрики

| Поле  | Описание | Единицы | Диапазон / примечание |
|---|---|---|---|
| `n` | Порядковый номер принятой команды | шт. | Инкремент на каждый `set_speed` |
| `v` | Заданная линейная скорость | мм/с | ±300 (`V_MAX_MM_S`) |
| `w` | Заданная угловая скорость | рад/с | ±ω_max ≈ 3.24 (`2·300 / WHEELBASE`, WHEELBASE = 185 мм) |
| `mL`  | Измеренная скорость левого колеса | мм/с | Квант 8.54 мм/с (1 тик энкодера за 10 мс); обновляется только в состоянии RUN |
| `mR`  | Измеренная скорость правого колеса | мм/с | То же, что и `mL` |
| `oL`  | Выход PID левого колеса | PWM | ±255 (значение ШИМ motor speed) |
| `oR`  | Выход PID правого колеса | PWM | ±255 |
| `iL`  | Интегральная составляющая PID левого колеса | усл. | Кламп ±500 (`PID_INTEGRAL_LIMIT`) |
| `iR`  | Интегральная составляющая PID правого колеса | усл. | ±500 |

### Особенности

* На стопе (`stop`/`power_stop`) измеренная скорость замирает: энкодеры не читаются вне состояния RUN, поэтому `mL/mR` могут показывать последнее значение перед остановкой, а не ноль.
* В консольном пульте (`controller.py`) последние 50 строк `ack` выводятся в панель телеметрии (свежие сверху, свежайшая строка подсвечена).

## Черновик

### Сделать запись в файл полного лога с телеметрией для сеанса работы в консоли управления

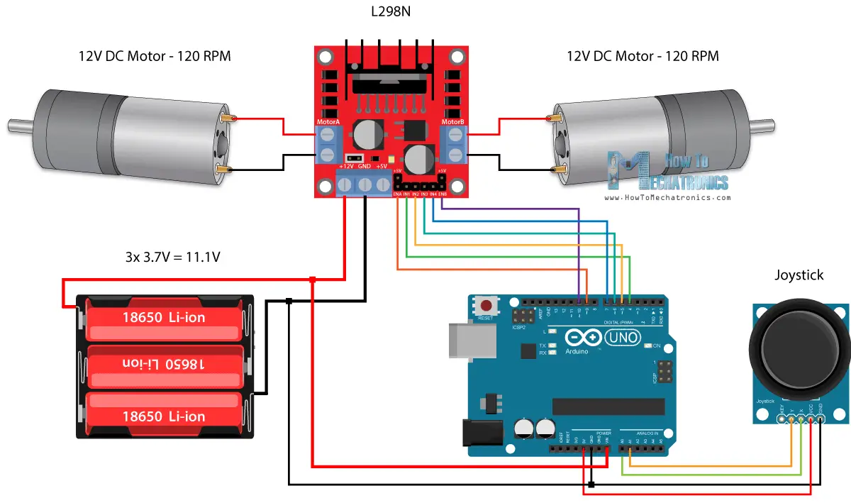
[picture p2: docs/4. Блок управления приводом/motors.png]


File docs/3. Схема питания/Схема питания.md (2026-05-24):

<!-- TOC -->
  * [Расчёт потребления](#расчёт-потребления)
    * [Список потребителей](#список-потребителей)
    * [Параметры потребителей](#параметры-потребителей)
      * [Мотор](#мотор)
      * [Микроконтроллер](#микроконтроллер)
      * [Одноплатный компьютер](#одноплатный-компьютер)
      * [Лидар](#лидар)
      * [Ультразвуковой дальномер](#ультразвуковой-дальномер)
      * [Камера](#камера)
    * [Суммарное потребление](#суммарное-потребление)
  * [Источник питания](#источник-питания)
    * [Параметры аккумулятора](#параметры-аккумулятора)
      * [Вольтаж](#вольтаж)
      * [Размер](#размер)
      * [Ёмкость](#ёмкость)
      * [Ток разряда](#ток-разряда)
    * [Выбор аккумулятора](#выбор-аккумулятора)
      * [Li-Po](#li-po)
        * [Особенности](#особенности)
        * [Параметры](#параметры)
        * [Выбор модели](#выбор-модели)
        * [Зарядка](#зарядка)
        * [Защита от переразряда](#защита-от-переразряда)
      * [Li-Ion](#li-ion)
        * [Особенности](#особенности-1)
        * [Параметры](#параметры-1)
        * [Выбор модели](#выбор-модели-1)
        * [Сборка](#сборка)
          * [Сварка](#сварка-)
          * [Батарейный отсек](#батарейный-отсек)
          * [Без защиты](#без-защиты)
          * [С защитой](#с-защитой)
    * [Итого по источнику питания](#итого-по-источнику-питания)
  * [Преобразователи напряжения](#преобразователи-напряжения)
    * [Параметры](#параметры-2)
      * [Понижающий DC-DC Step Down преобразователь LM2596](#понижающий-dc-dc-step-down-преобразователь-lm2596)
      * [Понижающий DC-DC Step Down преобразователь XL4005/XL4015](#понижающий-dc-dc-step-down-преобразователь-xl4005xl4015)
      * [Понижающий DC-DC Step Down преобразователь XL4016E1](#понижающий-dc-dc-step-down-преобразователь-xl4016e1)
      * [UBEC-7A](#ubec-7a)
      * [Понижающий DC-DC Buck преобразователь Cedar 10A](#понижающий-dc-dc-buck-преобразователь-cedar-10a)
    * [Итого по преобразователям](#итого-по-преобразователям)
  * [Электрическая схема](#электрическая-схема)
  * [3D Модель](#3d-модель)
  * [Реализация](#реализация)
  * [Список компонентов](#список-компонентов)
  * [Ссылки](#ссылки)
<!-- TOC -->

Для питания компонентов бота нам необходимо выбрать источник питания - аккумулятор с
подходящими параметрами.

Помимо источника питания могут понадобиться преобразователи уровня напряжения, так как
разные потребители могут использовать различные напряжения для питания.

## Расчёт потребления

Для каждого потребителя необходимо определить напряжение и ток. Имея эти данные получим общую потребляемую мощность для
расчёта параметров источника питания.

### Список потребителей

| Потребитель | Параметры/модель | Количество |
|---|---|---|
| Мотор | JGB37-520 encoder motor Smart car motor DC 12V small motor car kit speed motor. 178 RPM | 2 |
| Микроконтроллер | Arduino Nano 3.0 Mini | 2 |
| Одноплатный компьютер | RPI 4 Model B | 1 |
| Лидар | Xiaomi Mijia STYTJ02YM | 1 |
| Ультразвуковой датчик | HY-SRF04 SRF04 Ultrasonic Distance Sensor | 1 |
| Камера | Pi Camera Module 3 | 1 |

### Параметры потребителей

#### Мотор

Справочная информация по потреблению тока мотором:
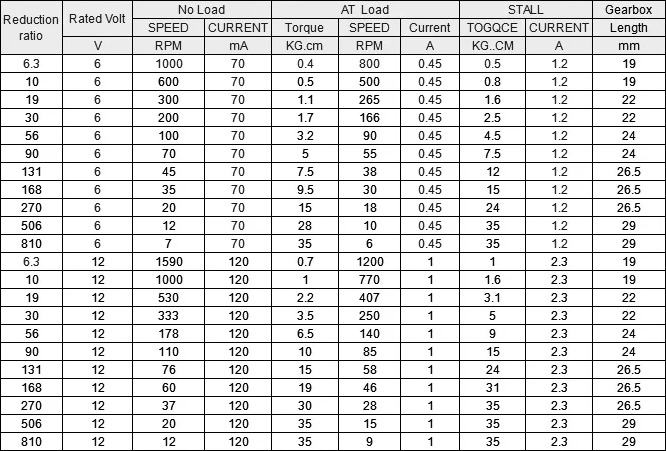
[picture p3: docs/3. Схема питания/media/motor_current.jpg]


В нашем случае строка 12V, 178 RPM. 

Под нагрузкой: 1A, стопор: 2.3A

| Модель | Min | Max  | Average |
|---|-----|---|---|
| 12V, 178 RPM | 1A  | 2.3A | 1.5A |

#### Микроконтроллер

Напряжение 5V (при наличии стабилизатора напряжения)

Потребление без учёта периферии:

| Модель | Min | Max | Average |
|---|---|---|---|
| Nano | 20 mA | 80 mA | 30 mA |

Максимальный ток с периферией может быть 380mA, но всю периферию мы считаем отдельно,
поэтому учитывать в потреблении не будем.

#### Одноплатный компьютер

Напряжение 5V

| Модель | Min | Max | Average |
|---|-----|-----|---|
| Raspberry Pi 4 Model B | 1A  | 3A  | 2A |
| Raspberry Pi 5 | 1A  | 3A  | 2A |
| Orange PI 6 Plus | 1A  | 3A  | 2A |

Максимальный ток с периферией для RPI 5 может быть 5A, но всю периферию мы считаем отдельно,
поэтому учитывать в потреблении не будем.

#### Лидар

Напряжение 5V

Потребление лидара постоянное 350 mA ([Источник](https://www.youtube.com/watch?v=S_xONJO4-Q0))

#### Ультразвуковой дальномер

Напряжение 5V

Потребление дальномера постоянное 15mA

#### Камера

Напряжение 5V

| Модель | Min | Max | Average |
|---|---|---|---|
| Raspberry Pi Camera Module 3 | 220mA | 600mA | 450mA |

### Суммарное потребление

Для расчётов будем использовать максимальные токи для 
каждого потребителя, чтобы гарантировать надежную работу в самом экстремальном режиме:

| Потребитель | Напряжение | Ток средний | Ток максимальный |
|---|---|---|---|
| Мотор | 12V | 1.5 | 2.3A |
| Мотор | 12V | 1.5 | 2.3A |
| Микроконтроллер | 5V | 30mA | 80mA |
| Микроконтроллер | 5V | 30mA | 80mA |
| Одноплатный компьютер | 5V | 2A | 3A |
| Лидар | 5V | 350mA | 350mA |
| Ультразвуковой датчик | 5V | 15mA | 15mA |
| Камера | 5V | 450mA | 600mA |

Итого мы получаем:

Максимальная мощность:
* Напряжение: 12V, максимальный длительный ток: 4.6A (силовая)
* Напряжение: 5V, максимальный длительный ток: 4.1A (электроника)
* Общая мощность: 12V*4.6A + 5V*4.1A = 75.7 Вт; с запасом 85 Вт

Средняя мощность: 

* Напряжение: 12V, ток: 3A (силовая)
* Напряжение: 5V, ток: 2.9A (электроника)
* Общая мощность: 12V*3A + 5V*2.9A = 50.5 Вт; с небольшим запасом 55 Вт

## Источник питания
### Параметры аккумулятора

Критерии выбора:
* Вольтаж
* Размер
* Емкость
* Ток разряда (C-рейтинг)

#### Вольтаж

У нас две группы потребителей 5 и 12 вольт. Причем 12 вольт это силоваая группа. 
В любом случае нам нужно использовать адаптер напряжения для какой-то из групп потребителей. 
Выглядит оптимальным для 5 вольтовых потребителей использовать понижающий преобразователь напряжения,
а для 12-вольтовых потребителей хотелось бы обойтись без адаптера.

Поэтому нужен аккумулятор на 12 V

#### Размер

Для комфортного размещения в корпусе бота нам нужно уложиться в размеры 90x65x40 мм:

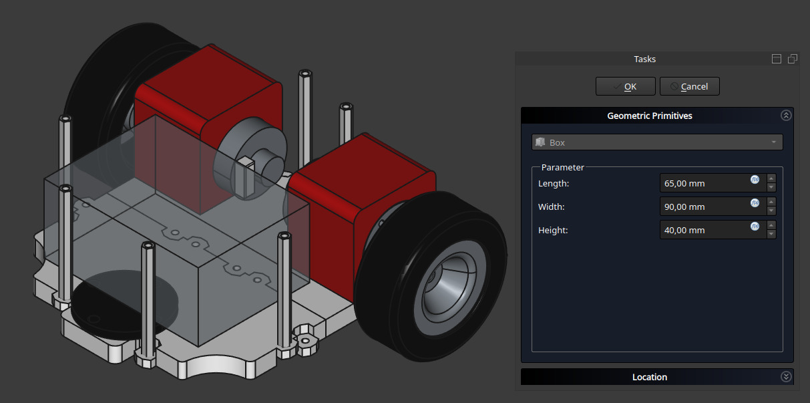
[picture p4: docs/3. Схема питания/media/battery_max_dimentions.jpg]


#### Ёмкость

Ёмкость будет определять время работы от одной зарядки.
Так как у нас потребляется разное напряжение, будем проводить расчёты в ватт-часах.

Ранее мы посчитали среднее потребление и получили 55 ватт.
Ёмкость аккумуляторов обычно указывается в мА·ч, поэтому приведём к мА·ч:

Мощность за час: U·I. Размерность В·А·ч.

Ампер-часы: мА·ч ≈ Вт·1000/U = 55·1000/12 = 4584 мА·ч

То есть для работы от одной зарядки в течение часа нам потребуется аккумулятор ёмкостью 4584 мА·ч.

Минимальное время работы от одной зарядки определим в 30 минут. Поэтому ёмкость аккумулятора должна быть не
менее 2200 mAh.

#### Ток разряда

* Средняя потребляемая мощность 55 ватт 
* При напряжении питания 12 вольт получаем средний ток разряда 55/12 = 4.6A.
* Максимальная потребляемая мощность 85 ватт.
* Максимальный ток разряда 85/12 = 7A. 

Если использовать аккумуляторы с максимальным током разряда 7А, то не будет запаса на рост или какие-то непредвиденные ситуации.
Для надежной работы заложим двойной запас по току разряда - 15A. 

Итого: ток длительного разряда должен быть не менее 15 ампер.

Ток разряда определяется параметром C-рейтинг.

Посчитаем C-рейтинг для аккумулятора 2200 mAh и потребления 15A:
* 15A/2.2Ah = 7C (округлено)

Итого: ток разряда должен быть 15A (рейтинг 7C или выше)

### Выбор аккумулятора

Параметры:
* 90x65x40
* 12 V
* от 2200 mAh
* от 15A (7C)

Под наши требования подходят два варианта аккумуляторов:

* LiPo аккумуляторы
* LiIon аккумуляторы

Напряжение одной ячейки составляет от 3 до 4.2 вольта в зависимости от уровня заряда. Общий вольтаж аккумуляторов изменяется количеством 
последовательно соединенных ячеек - 1S, 2S, 3S и т.д.
Для увеличения тока разряда аккумуляторные ячейки соединяются параллельно - 1P, 2P, 3P и т.д.
Остальные варианты аккумуляторов не подходят из-за малых токов разряда (NiMH) или больших размеров (свинцовые)

#### Li-Po

##### Особенности

Особенности LiPo аккумуляторов:

* Большая вариативность форм, ёмкости, вольтажа. 
* Выдают большие токи 30–100C. 
* Относительно малые габариты и вес. 
* Требуется обязательно защита от переразряда. 
* Требуют осторожности в использовании, так как упакованы в мягкий корпус.

##### Параметры
Итого нам нужен LiPo аккумулятор: 
* 3S(~12v)
* от 2200mAh
* менее 90 мм в длину 
* менее 65x40 мм в сечении.    

##### Выбор модели
Выбираем 3S аккумулятор из таблицы:

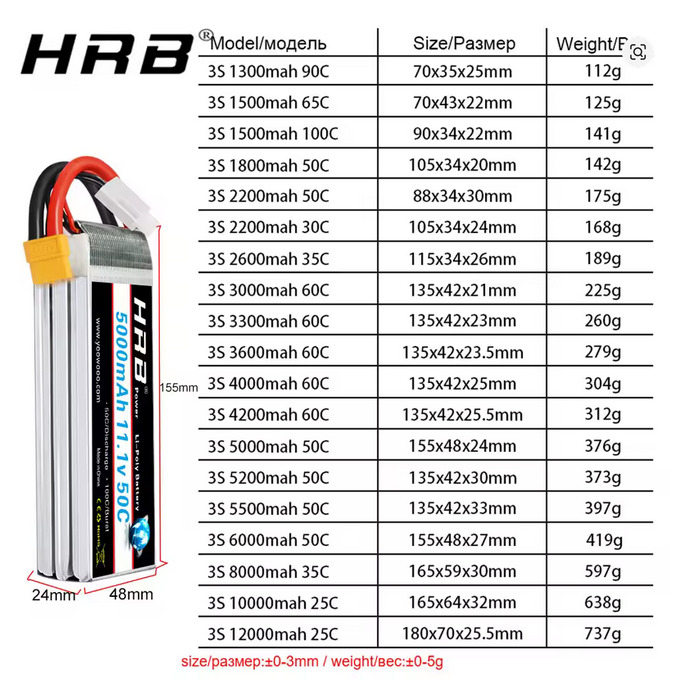
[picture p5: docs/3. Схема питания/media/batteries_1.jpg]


Под наши критерии полностью подходит только вариант 3S 2200 mAh 50C (88x34x30)

* По размерам проходит.
* Ток разряда 50C — это 110A. Для нашей задачи огромный запас.
* Емкость 2200 mAh - это чуть меньше нашей границы, но в целом подходит.

##### Зарядка

Для заряда необходимо использовать зарядное устройство с функцией балансировки заряда.

Подходит универсальное зарядное устройство IMAX B6/B6AC:

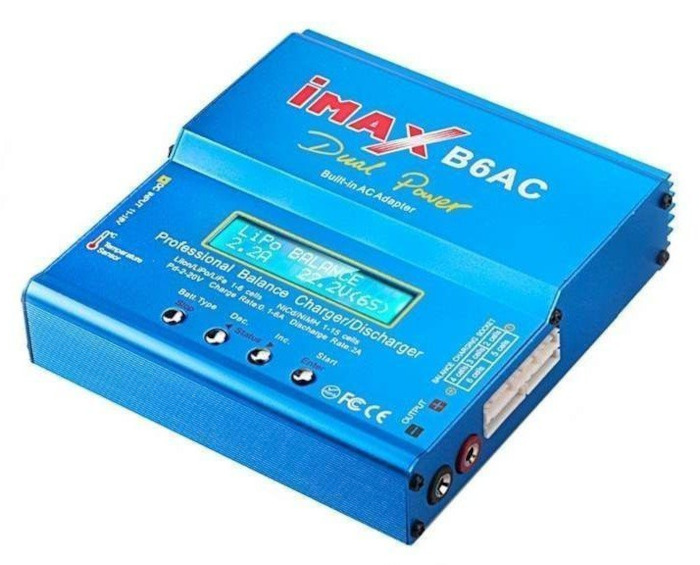
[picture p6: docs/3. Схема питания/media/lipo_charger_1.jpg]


##### Защита от переразряда
Литиевые аккумуляторы повреждаются при сильном разряде.

Сводная таблица напряжений для LiPo 3S с процентом разряда:

| Состояние | Напряжение всего аккумулятора | Напряжение на банке | **Примерный % остатка** | Примечание |
|:---|:---|:---|:---|:---|
| **Полный заряд** | 12.6 В | 4.20 В | **100%** | Максимум для зарядки |
| **Начало рабочего разряда** | ~12.2 В | ~4.07 В | **~80%** | Быстрый спад под нагрузкой, норма |
| **Середина разряда** | ~11.7 В | ~3.90 В | **~60%** | Стабильная рабочая зона |
| **Рекомендуемый предел для остановки** | **~11.1 В** | **~3.70 В** | **~20%** | **Самое время заканчивать работу!** |
| **Начало "обрыва"** | ~10.8 В | ~3.60 В | **~10%** | Опасная зона! Напряжение начнет падать очень быстро |
| **Критический разряд (Стоп!)** | **9.6 В** | **3.2 В** | **~0%** | Жесткий предел, дальше нельзя. Аккумулятор поврежден. |
| **Абсолютный минимум (Убийство аккумулятора)** | 9.0 В | 3.0 В | **—** | Необратимое повреждение, опасность возгорания |

График разряда:

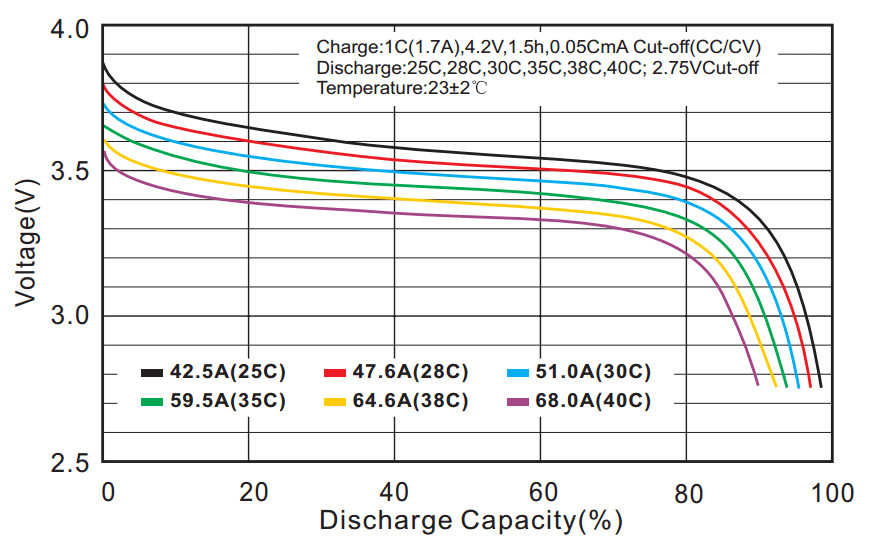
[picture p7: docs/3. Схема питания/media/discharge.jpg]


Для защиты от переразряда в идеале нужно использовать плату BMS, но для LiPo аккумуляторов допустимо не использовать BMS
и полагаться на индикаторы в виде измерителя напряжения со звуковым сигналом. При достижении минимального порога
напряжения на элементе аккумулятора устройство пищит и мигает светодиодами.
Учитывая, что у нас не коптер и есть возможность оперативно отключить бота,
можно ставить отсечку на 3.5 вольта на банку. Общее напряжение использовать нельзя,
так как может быть перекос и какая-то банка сильно разрядится.

Устройство для защиты от переразряда:

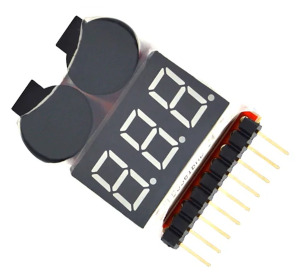
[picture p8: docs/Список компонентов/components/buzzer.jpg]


#### Li-Ion

##### Особенности

Особенности LiIon аккумуляторов:

* Поставляются в виде отдельных ячеек. 
* Выдают средние токи 1-10C.
* Средние габариты и вес.
* Могут быть как с встроенной защитой, так и без. 
* Безопасны, так как имеют металлическую оболочку.

##### Параметры
Итого нам нужен LiIon аккумулятор:
* 3S (~12 V)
* от 2200 mAh
* от 15A (7C)

Для формирования 12 V нам необходимо последовательное соединение трех ячеек (3S). При последовательном соединении
ток разряда не меняется и остается та же емкость (mAh). Если необходимый ток при этом не обеспечивается, 
то применяется параллельное соединение ячеек. Ток разряда умножается на количество параллельно соединенных ячеек (2P,3P и т.д.).
В нашем случае мы уже имеем 3S соединение и для увеличения тока в два раза можно использовать схему 3S2P, либо использовать
две сборки 3S1P с параллельным соединением. Также хороший вариант использовать отдельные сборки для разных 
потребителей - один для силовой и один для электроники.

##### Выбор модели

Наиболее распространенные модели это LiIon аккумуляторы формфактора 18650:
* Диаметр 18 мм
* Высота 65 мм

Нам нужно либо 3 ячейки, либо 6 ячеек. 
В сборке получаем следующие размеры:

* 3 ячейки - 54x65x18 мм
* 6 ячеек - 54x65x36 мм

Оба варианта проходят по размерам.

Нам нужны высокотоковые LiIon аккумуляторы 18650

| Модель | Ток разряда | Емкость |
|---|---|---|
| Samsung INR18650-30Q  | 15A | 3000mAh |
| Molicel INR18650-P30B | 30A | 3000mAh |
| BAK N18650CNP | 30A | 2500mAh |
| EVE INR18650/35V | 10A | 3500mAh |

Можно использовать 30-амперные аккумуляторы в варианте 3S1P. Итоговая емкость будет 3000 mAh. 
Аккумуляторы с токами ниже 20 ампер не стоит использовать в варианте 3S1P и собирать 3S2P. 
Если делать сборку 3S2P, то в итоге можно получить 6000 mAh. При среднем потреблении 55 ватт 
это будет почти полтора часа. Для начала можно использовать 3S1P, так как это дешевле и проще.
В дальнейшем можно попробовать 3S2P.

##### Сборка

По конструкции сборки есть два варианта:

1. Сварка полосками
2. Использование батарейных отсеков 

В теории можно купить готовые сборки, но зачастую в продаже сборки из 
слаботочных ячеек и нормальных сходу найти не получается.

###### Сварка 
Ячейки соединяются лентой:

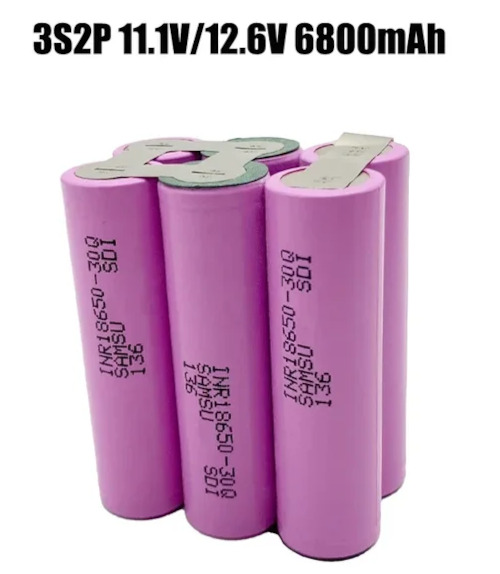
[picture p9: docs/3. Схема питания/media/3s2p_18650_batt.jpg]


Такой вариант по размерам самый оптимальный, но сварка требует специального оборудования, поэтому
вариант не очень доступный. Можно пробовать паять без сварки, но есть риск повредить батарею.

###### Батарейный отсек

Отсек выглядит так:

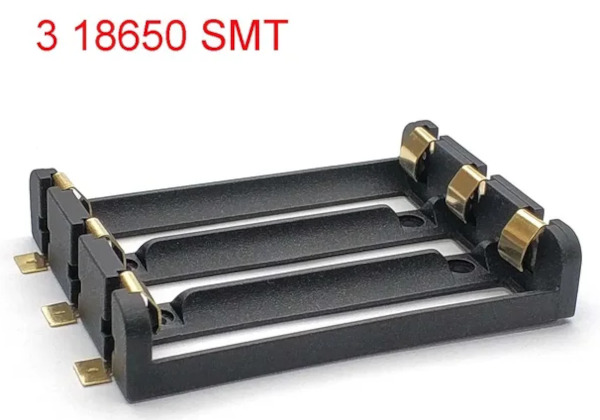
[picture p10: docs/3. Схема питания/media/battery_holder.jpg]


Искать по запросу "3S 18650 Battery Storage Case SMD SMT THM 3 18650 Battery Box 18650 Battery Holder with Bronze Pins"

С батарейным отсеком не требуется пайка к аккумулятору, но итоговые размеры 
будут чуть больше. Размеры отсека 77 * 61 * 15 миллиметров, то есть в высоту ничего не добавляется, в ширину и глубину 
добавляется 12 и 7 мм соответственно, Эти габариты укладываются в требуемые для проекта.

По схеме защиты и заряду есть два варианта:

1. Без защиты от переразряда и перезаряда. 
2. С защитой от переразряда и балансировкой

###### Без защиты
В этом случае используются только ячейки без плат защиты. Этот вариант подходит при наличии 
зарядного устройства с балансировкой заряда и внешнего индикатора разряда. Такой вариант исполнения по
использованию аналогичен LiPO сборкам. Нужно контролировать разряд с помощью индикаторов и использовать
специальные зарядные устройства с контролем уровня заряда. 

Для заряда подходит универсальное зарядное устройство IMAX B6/B6AC:



Если сборка сделана на батарейном отсеке, то можно заряжать аккумуляторы по отдельности зарядкой для 18650:

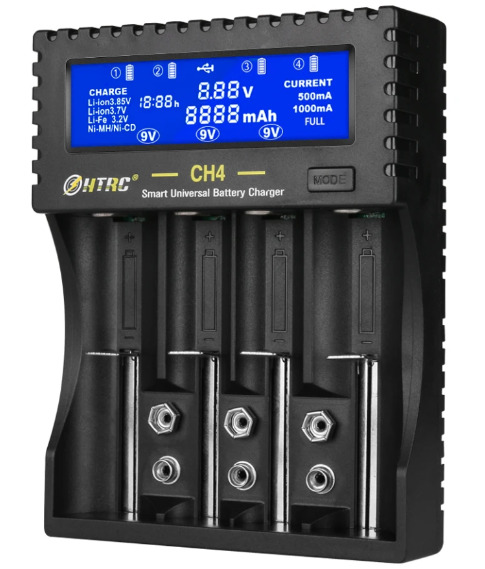
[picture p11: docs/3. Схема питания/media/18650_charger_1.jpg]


Для контроля разряда нужно использовать индикаторы в виде измерителя напряжения со звуковым сигналом. 
При достижении минимального порога напряжения на элементе аккумулятора устройство пищит и мигает светодиодами.

Электрическая схема:





В итоге должно получиться что-то такое в варианте со сваркой:

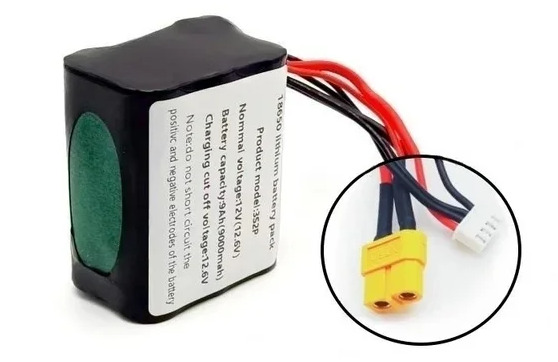
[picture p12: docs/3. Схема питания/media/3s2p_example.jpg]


Картинки варианта с батарейным отсеком нет, но суть понятна.

###### С защитой

Вариант с защитой самый надежный и безопасный. В этом варианте 
используется плата BMS (Battery Management System). Плата BMS обеспечивает разные функции:

* Защита от переразряда 
* Защита от короткого замыкания
* Балансировка заряда. Балансировка позволяет выравнять все элементы по уровням напряжения.

Лучше всего использовать BMS с полной поддержкой всех функций. Это даст максимальное удобство.

Схема подключения:

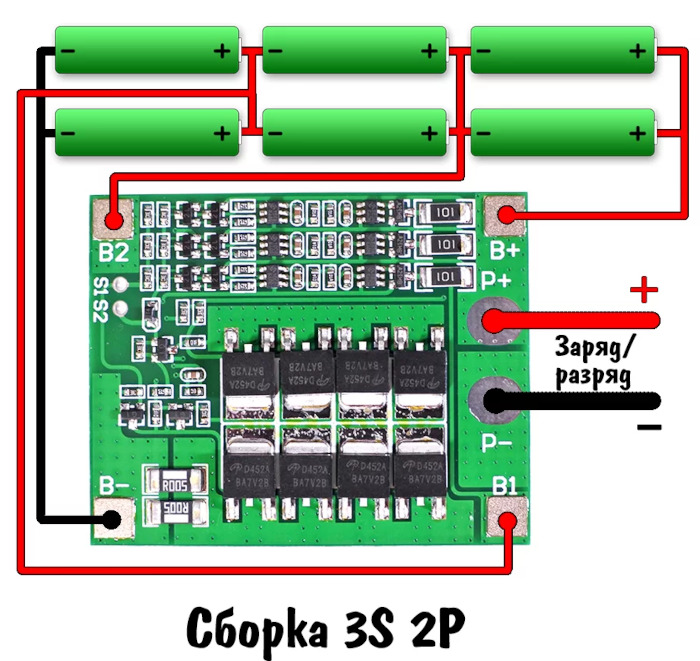
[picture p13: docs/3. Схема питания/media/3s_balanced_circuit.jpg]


Искать по запросу "1S/2S/3S/4S/5S Li-ion 18650 Lithium Battery Charger Lipo Cell Module PCB BMS Protection Board For Drill Motor with Balance"

Для зарядки и нагрузки можно использовать один разъем XT60, но лучше добавить отдельный разъем для 
зарядки, так как зарядники чаще всего идут с разъемом 2.1 мм. 
Модели заряжающих устройств отличаются силой тока заряда. Для выбора тока заряда используется формула: 
Ток заряда I = 0.5*емкость (для 2200 mAh = 1100 mA)

Для зарядки будет использоваться простое зарядное устройство вида:

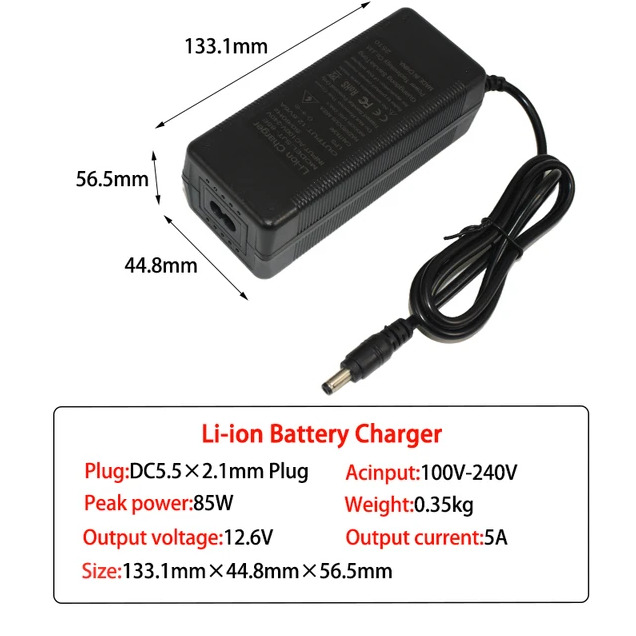
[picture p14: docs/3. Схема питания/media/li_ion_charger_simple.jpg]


Искать по запросу "Li-ion 12.6V 5A Lithium Battery Charger for 3S 18650 Li-ion Packs"

### Итого по источнику питания

Наиболее оптимальным видится вариант Li-Ion 3S1P с BMS платой. В этом случае можно сделать несъёмный
источник питания и просто подключать зарядку к боту. Максимальное удобство и безопасность.
В текущем проекте будет использоваться Li-Po аккумулятор, так как он уже есть в наличии и есть
зарядник с балансировкой.

## Преобразователи напряжения

### Параметры

Для потребителей, требующих 5 вольт, будем использовать понижающий преобразователь напряжения.
Ранее мы посчитали, что максимальный ток будет 4A. Необходимо иметь запас, поэтому
нужно ориентироваться на 10A

#### Понижающий DC-DC Step Down преобразователь LM2596

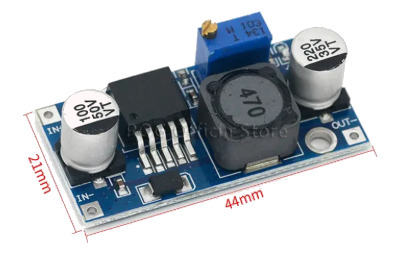
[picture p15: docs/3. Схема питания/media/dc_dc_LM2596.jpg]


* Входное напряжение: 4.5V - 28 Вольт
* Выходное напряжение: 0.8 - 20 Вольт (регулируемое)
* Максимальный выходной ток: 3A
* Рекомендуемый выходной ток: 2A
* КПД: 96%

Не проходит по току для одноплатного компьютера. В обзорах указано, что при токе 3 А
может работать не более нескольких минут. 

#### Понижающий DC-DC Step Down преобразователь XL4005/XL4015

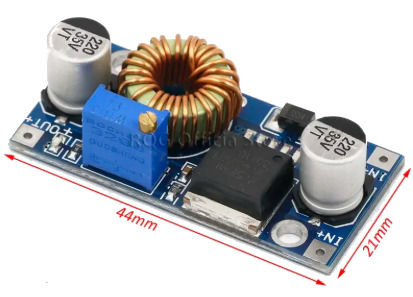
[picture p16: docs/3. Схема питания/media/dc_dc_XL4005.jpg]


* Входное напряжение: 4 - 38 Вольт
* Выходное напряжение: 1.25 - 32 Вольт (регулируемое)
* Максимальный выходной ток: 5A (рекомендуется установить радиатор)
* Рекомендуемый выходной ток: 4.5A
* КПД: 96%

Один преобразователь будет работать на пределе и без запаса, поэтому можно использовать два преобразователя
для разных групп потребителей. 
Самое большое потребление будет у одноплатного компьютера — 3–4A (без питания периферии). Можно выделить 
один преобразователь только под одноплатник, а остальных потребителей подключить через второй преобразователь.

#### Понижающий DC-DC Step Down преобразователь XL4016E1

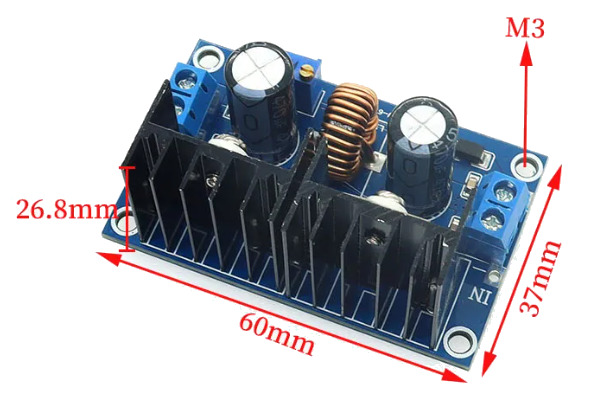
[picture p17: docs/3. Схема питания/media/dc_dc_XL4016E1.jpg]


* Входное напряжение: от 4 до 38 V
* Выходное напряжение: от 1.25 до 36 V
* Выходной ток: 8A
* Выходная мощность: до 250 Вт
* КПД: до 95%

Эта модель потянет всех потребителей, но она имеет большой размер, поэтому не так удобна.

#### UBEC-7A

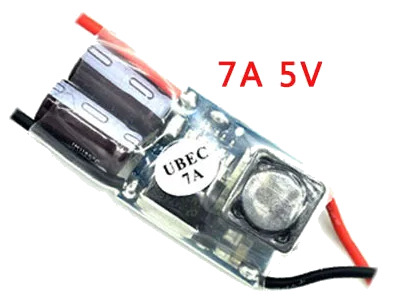
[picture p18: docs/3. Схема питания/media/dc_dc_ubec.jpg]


* Входное напряжение 5.5V-35V (2-8S LIPO)\
* Output voltage: 5.25V±0.5V
* Выходной длительный ток: 6A
* Пиковый ток: 7.5A 20 sec

Потенциально можно использовать UBEC, которые используются в RC моделях, но у них 
большой разброс выходного напряжения и одноплатный компьютер может не запуститься.

#### Понижающий DC-DC Buck преобразователь Cedar 10A

High Power DC-DC Buck Module 9-14V to 5V Step down Voltage Power Supply Regulator for Power Supply Module

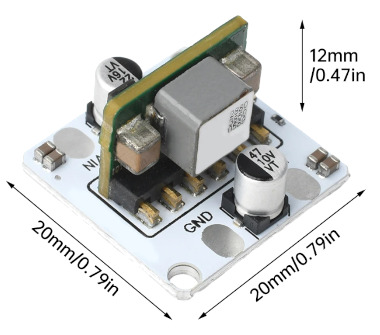
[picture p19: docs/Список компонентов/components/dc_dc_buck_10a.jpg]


* Входное напряжение: DC 9-14V
* Выходное напряжение: 5V±0.1V
* Выходной длительный ток: 10A, Max

Идеальный по размеру и по мощности, но нужно тестировать на соответствие заявленным параметрам.
Найден [обзор конвертера](https://www.youtube.com/watch?v=GEXZrJfdjXs), из которого следует, 
что конвертер имеет большой запас по току и подходит нам.

### Итого по преобразователям

Идеально подходит Cedar DC-DC Buck преобразователь 10A. 

## Электрическая схема

С учётом всех компонентов электрическая схема будет такая:



Для выключения питания будем использовать кнопочный выключатель 
KCD1 21*15mm ON-OFF Boat Car Rocker Switch:



Провода силиконовые 18AWG.
Для 12 V — разъёмы XT60.
Для 5 V — разъёмы XT30.

## 3D Модель
 
Необходимо разместить компоненты на платформе. 

* Для аккумулятора реализован держатель, в который его можно вставить и извлекать для зарядки. 
* Преобразователь напряжения крепим к платформе через подставки.
* Выключатель очень хорошо держится между стойками в задней части.
* Сигнализатор разряда подключается к аккумулятору и не требует крепления. 

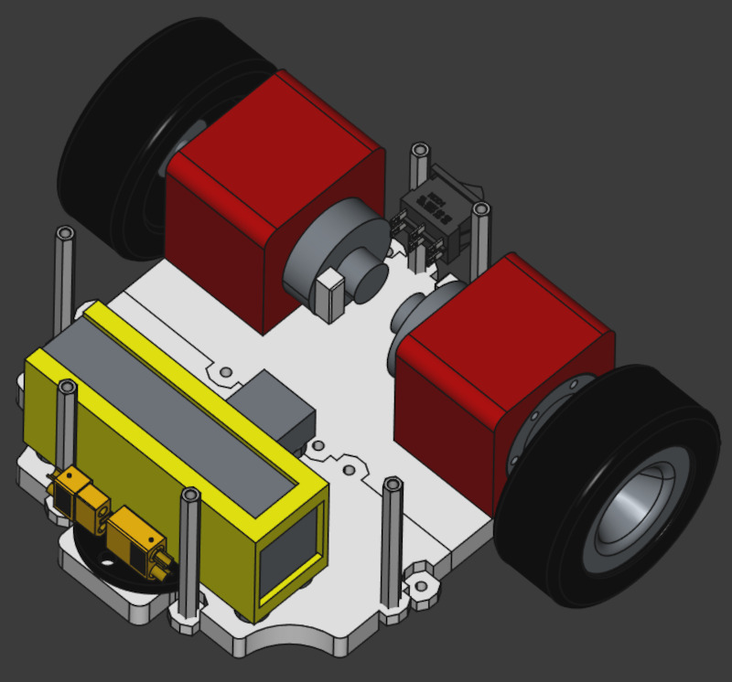
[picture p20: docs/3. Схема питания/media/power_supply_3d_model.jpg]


## Реализация

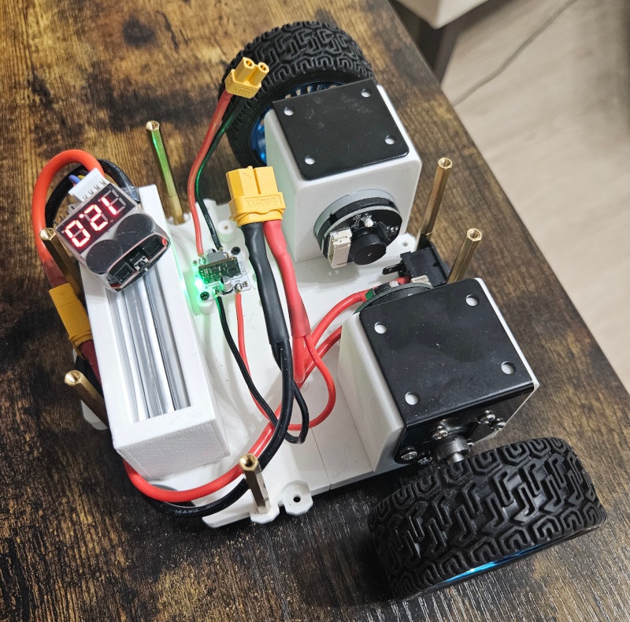
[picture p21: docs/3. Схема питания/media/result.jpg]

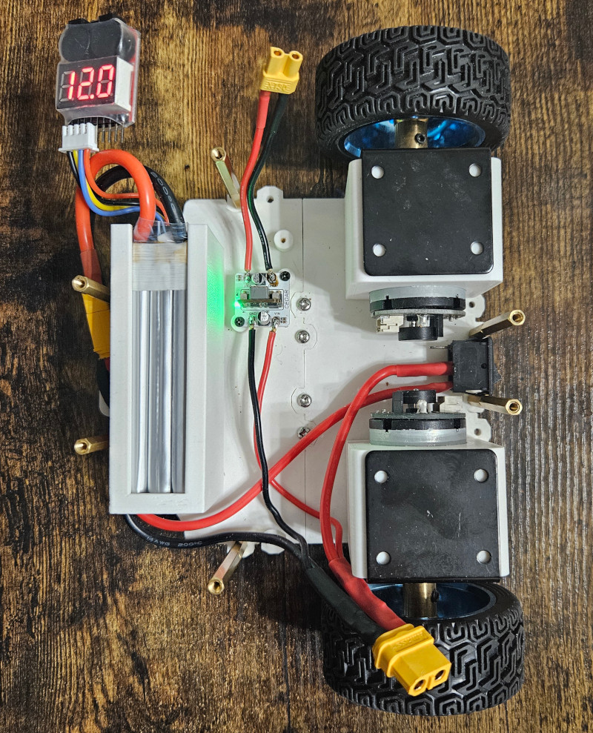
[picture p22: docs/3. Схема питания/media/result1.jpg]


## Список компонентов

| Компонент | Модель | Картинка |
|---|---|---|
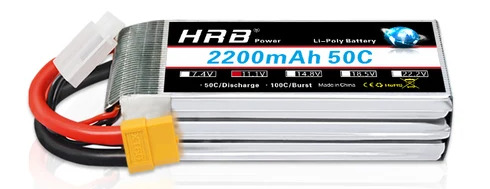
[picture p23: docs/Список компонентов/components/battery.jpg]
| Аккумулятор | HRB 3S LiPo Battery 11.1V 2200mAh 50C for RC Car with Deans Plug XT60 Connector For RC Car Helicopter Drone Boat Airplane |  |
| Защита аккумулятора | 1pcs or 4pcs Hot Sell 2s 3s 4s 5s 6s 7s 8S 1-8S LED Low Voltage Buzzer Alarm Lipo Voltage Indicator Checker Tester Wholesale |  | 
| Преобразователь напряжения | Cedar High Power DC-DC Buck Module 9-14V to 5V Step down Voltage Power Supply Regulator for Power Supply Module |  |
| Провод | Провод 18AWG (0.8 мм2) в силиконовой изоляции. Луженая медь. 1 метр - черный. 1 метр - красный. | |
| Провод | Провод 14AWG (2 мм2) в силиконовой изоляции. Луженая медь. 1 метр - черный. 1 метр - красный. | |
| Выключатель клавишный | KCD1 21*15mm ON-OFF Boat Car Rocker Switch |  |
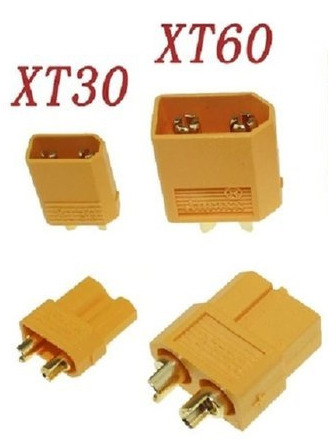
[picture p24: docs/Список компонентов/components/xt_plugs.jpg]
| Разъемы для 12 V | XT60 Male/Female |  |
| Разъемы для 5v | XT30 Male/Female | |
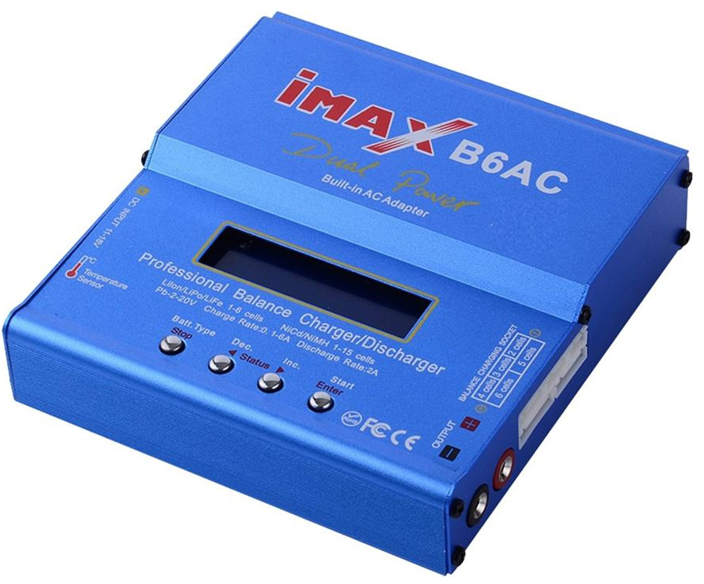
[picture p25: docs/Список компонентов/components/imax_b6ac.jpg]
| Зарядное устройство | IMAX B6AC 80W RC Balance Charger+ |  |

## Ссылки

Для анализа использовались следующие источники:

* http://rc-aviation.ru/rc-ob/1294-accum/2219-samodelnie-liion
* https://alexgyver.ru/18650/
* https://mysku.club/blog/china-stores/40848.html
* https://magzaryada.ru/
* https://supereyes.ru/articles/power_supply/kak-vybrat-dc-dc-preobrazovatel/
* https://youtu.be/hPHiYvfqF7c?si=IJL5UCo2Ozq4r1-J
* https://www.youtube.com/watch?v=GEXZrJfdjXs

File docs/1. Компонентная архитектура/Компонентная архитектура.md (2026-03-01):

<!-- TOC -->
* [Компонентная архитектура](#компонентная-архитектура)
  * [Требования](#требования)
  * [Компоненты](#компоненты)
    * [Централизованная схема](#централизованная-схема)
    * [Распределенная схема](#распределенная-схема)
  * [Интерфейсы](#интерфейсы)
    * [SPI](#spi)
      * [Количество проводов](#количество-проводов)
      * [Количество устройств](#количество-устройств)
      * [Количество портов на RPI](#количество-портов-на-rpi)
      * [Пропускная способность порта](#пропускная-способность-порта)
      * [Выводы](#выводы)
    * [I2C](#i2c)
      * [Количество проводов](#количество-проводов-1)
      * [Количество устройств](#количество-устройств-1)
      * [Количество портов на RPI](#количество-портов-на-rpi-1)
      * [Пропускная способность порта](#пропускная-способность-порта-1)
      * [Выводы](#выводы-1)
    * [UART](#uart)
      * [Количество проводов](#количество-проводов-2)
      * [Количество устройств](#количество-устройств-2)
      * [Количество портов на RPI](#количество-портов-на-rpi-2)
      * [Пропускная способность порта](#пропускная-способность-порта-2)
      * [Выводы](#выводы-2)
    * [USB (UART over USB)](#usb-uart-over-usb)
      * [Количество проводов](#количество-проводов-3)
      * [Количество устройств](#количество-устройств-3)
      * [Количество портов на RPI](#количество-портов-на-rpi-3)
      * [Пропускная способность порта](#пропускная-способность-порта-3)
      * [Выводы](#выводы-3)
    * [Итого по интерфейсам](#итого-по-интерфейсам)
  * [Итого по архитектуре](#итого-по-архитектуре)
<!-- TOC -->

# Компонентная архитектура

## Требования

Глобально у нас есть три задачи:

* Сбор информации с различных датчиков
* Анализ состояния системы
* Управление двигателями для изменения положения в пространстве. 

Центральный компонент это блок управления на базе одноплатного компьютера. Будем ориентироваться на RPI5 и Orange PI 5 plus.

На входе у нас могут быть следующие источники информации:

* Камера
* Лидар
* Датчик линии
* Датчик расстояния
* Энкодеры моторов

На выходе мы управляем моторами:

* Драйвер моторов

## Компоненты

### Централизованная схема

При подключении всех компонентов напрямую к центральному блоку мы получаем следующую организацию компонентов:



Такая схема работы имеет ряд недостатков:

* Для работы с периферией часто нужен аналогово-цифровой преобразователь. 
У одноплатников АЦП либо отсутствует, либо имеет ограничения. В Raspberry PI АЦП нет.
* Работа с энкодерами моторов требует формирования импульсов широтно-импульсной модуляции. 
В одноплатниках поддержка шим ограничена. Например, на Raspberry PI есть только два аппаратных канала, остальные программные. 
* Низкоуровневая работа с периферией будет отнимать ресурсы от высокоуровневой работы. 

### Распределенная схема

Для устранения озвученных проблем мы выносим часть логики управления в отдельные компоненты — блок управления моторами и блок датчиков. 

Это позволит нам реализовать низкоуровневое управление с помощью микроконтроллеров, таких как Arduino. 
В микроконтроллерах есть как аппаратная реализация ШИМ, так и АЦП. Таким образом мы получаем гибкую архитектуру 
с возможностью оптимизировать и заменять компоненты внутри блоков без влияния на всю систему. 
При необходимости можно будет менять как одноплатник, так и контроллеры. Например, вместо Arduino можно использовать 
более продвинутые и мощные платы Bluepill или Blackpill на контроллере STM, а вместо малины использовать 
Orange PI 5 plus с нейропроцессором для аппаратного ускорения работы AI и нейросетей.

Получаем децентрализованную схему:



В этом варианте часть устройств подключается напрямую к центральному блоку управления, а остальные к 
контроллерам. Каждый контроллер управлять различным количеством устройств в зависимости от ситуации. 
Количество контроллеров также может меняться.

## Интерфейсы

Мы определили точки взаимодействия между компонентами. Далее необходимо определить физический интерфейс для подключения
устройств и контроллеров. Пока ограничимся описанием для основного блока. Работу контроллеров с устройствами можно 
рассмотреть позднее при детальной проработке внутренней схемы управляемых блоков.

Камеру напрямую подключаем к одноплатнику по интерфейсу CSI (Camera Serial Interface).

Лидар тоже подключаем напрямую через серийный порт UART. Возможно позже это будет изменено. 

Для взаимодействия между контроллерами и одноплатником есть следующие варианты: SPI, UART, USB, I2C. Нам необходимо 
подключить минимум два контроллера, а в будущем возможно и больше поэтому важно это учесть при выборе интерфейса. 
Для нас важны следующие параметры:

* Сложность подключения (количество проводов для подключения, необходимость преобразователей уровней напряжения)
* Количество устройств подключаемых к одному физическому интерфейсу
* Количество физических интерфейсов на RPI и Orange PI
* Пропускная способность 

В части сравнения подключения не будем учитывать питание и GND так как у нас контроллеры в любом случае подключаются 
к этим проводам.

### SPI

#### Количество проводов

Для подключения одного контроллера к одноплатнику по SPI необходимо четыре провода:

* SCK (Serial clock)
* MOSI (Master OUT Slave IN)
* MISO (Master IN Slave OUT)
* CS (Chip select)



При этом каждое устройство использует общие провода SCK, MOSI, MISO и отдельный CS.
То есть количество проводов: 3 + N, где N - количество устройств.

#### Количество устройств

Теоретически можно подключить 128 устройств на один порт.
На практике мы ограничены количеством пинов на одноплатнике и получится подключить порядка 12 устройств.

#### Количество портов на RPI

Один основной (125 Mhz) и пять дополнительных (65 Mhz)

#### Пропускная способность порта

Максимальная: 125 Мбит/с
Реальная: 30-50 Мбит/с 

#### Выводы

Плюсы:
* Большая скорость передачи данных.
* Возможность параллельно передавать и принимать данные (full-duplex)

Минусы:
* Большое количество задействованных пинов.
* Необходимость преобразователей уровней напряжения.

При малом количестве устройств вариант подходящий. 

### I2C

#### Количество проводов

Два провода: 

* SDA (Serial data)
* SCL (Serial clock)



#### Количество устройств

Теоретически можно подключить 128 устройств на один порт. На практике при увеличении количества устройств на порт, 
скорость уменьшается за счет увеличения емкости шины. Для устранения этого эффекта необходимо 
подключать подтягивающие резисторы.

#### Количество портов на RPI

Три физических порта.

#### Пропускная способность порта

* 0.1 Мбит/с (Standard-mode)
* 0.4 Мбит/с (Fast-mode)
* 1 Мбит/с (Fast-mode Plus)
* 3.4 Мбит/с (High-speed mode) 

#### Выводы

Плюсы:

* Простота подключения.
* Большое количество устройств на порт.
* Остаются свободными пины.

Минусы:

* Работает либо на приём, либо на передачу в один момент времени (half-duplex).
* Низкая скорость передачи данных. 
* Зависимость скорости от емкости шины. Необходимо подключать резисторы.
* Необходимость преобразователей уровней напряжения.

Больше подходит для сбора информации с датчиков, чем для подключения контроллеров.

### UART

#### Количество проводов

Два провода:

* TX (Transmit)
* RX (Receive)



#### Количество устройств

На один порт можно подключить одно устройство.

#### Количество портов на RPI

Шесть портов. Из них четыре аппаратных и два программных.

#### Пропускная способность порта

Максимальная: 1 Мбит/с
Реальная: 0.115 Мбит/с

#### Выводы

Плюсы:

* Простота подключения.
* Возможность параллельно передавать и принимать данные (full-duplex)

Минусы:

* Одно устройство на порт.  
* Низкая скорость передачи данных.
* Большое количество задействованных пинов.
* Необходимость преобразователей уровней напряжения.

При малом количестве устройств вариант подходящий.

### USB (UART over USB)

#### Количество проводов

Один кабель USB

#### Количество устройств

На один порт можно подключить одно устройство. 
При наличии USB хаба можно подключить до 127 устройств.

#### Количество портов на RPI

Четыре порта USB (2 USB 2.0 + 2 USB 3.0)

#### Пропускная способность порта

USB 2.0: 480 Мбит/с (~40-60 UART портов)

#### Выводы

Плюсы:

* Простота подключения.
* Возможность параллельно передавать и принимать данные (full-duplex)
* Остаются свободными пины.
* Отсутствие преобразователей уровней напряжения.
* Большое количество устройств на порт (с хабом)

Минусы:

* Низкая скорость передачи данных (ограничение UART)

Максимально простой вариант с точки зрения подключения.
При небольшом количестве устройств подходит.

### Итого по интерфейсам

По итогам сравнения выглядит оптимальным использовать шину USB c виртуальными UART портами:
* Без USB хаба можно подключить 4 устройства. Этого достаточно.
* Скорость на каждое устройство будет 1 Мбита в секунду. Достаточно.
* Нет необходимости подключать преобразователи логических уровней.
* Не занимаем пины на GPIO.

## Итого по архитектуре

Итоговая компонентная архитектура:



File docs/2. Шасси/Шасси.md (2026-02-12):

<!-- TOC -->
  * [Шасси](#шасси)
    * [Исходные данные](#исходные-данные)
    * [3D модели компонентов](#3d-модели-компонентов)
      * [Мотор](#мотор)
      * [Колеса](#колеса)
      * [Роликовое колесо](#роликовое-колесо)
      * [Основание](#основание)
      * [Крепление мотора](#крепление-мотора)
    * [Итоговая 3D модель](#итоговая-3d-модель)
    * [Реализация](#реализация)
    * [Список компонентов](#список-компонентов)
<!-- TOC -->

## Шасси

### Исходные данные
* У нас есть базовая деталь для основания шасси.
* По размеру подходят моторы и колеса.



* В качестве переднего ролика можно использовать мебельный ролик.



Понятно, что базовая деталь нам не подходит и нужно делать свою реализацию.
Для компоновки нам понадобятся 3D модели всех компонентов.

### 3D модели компонентов

#### Мотор



#### Колеса



#### Роликовое колесо



#### Основание



#### Крепление мотора



### Итоговая 3D модель



### Реализация

Крепления моторов фиксируем на основании с помощью цианоакрилатного клея COSMOFEN.
Ролик я приклеил на тонкий двухсторонний скотч. В целом можно использовать любой способ крепления.
Моторы входят очень плотно и нет необходимости в креплении винтами.



### Список компонентов

| Компонент | Реализация | 3D Модель |
|---|---|---|
| Мотор с энкодером | JGB37-520 encoder motor Smart car motor DC 12V small motor car kit speed motor |  |
| Роликовое колесо | Self Adhesive Caster Mini Swivel Wheels Stainless Steel Universal Wheel 360 Degree Rotation Pulley for Furniture Trash Can |  |
| Колесо | Car Model 65MM Tyre Big Friction Wheel Toy Intelligent Car Robot Wheel Wheel DIY |  |
| Стойка 35mm,55m(35+20) | Solid Brass Copper M3 Hex Standoff Hexagon Pillar F-F Female-Female Spacer for PCB Board Motherboard |  |
| Основание шасси | 3D печать ([3D модели](https://github.com/makarov-na/turtle-bot-3d-models)) |  |
| Крепление мотора | 3D печать ([3D модели](https://github.com/makarov-na/turtle-bot-3d-models)) |  |

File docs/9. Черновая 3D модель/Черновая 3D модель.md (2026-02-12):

На данном этапе понимаем из каких основных компонентов состоит бот.
М

Компонентная диаграмма:



Схема питания:

Полный список компонентов:

| Компонент | Реализация | 3D Модель |
|---|---|---|
| Аккумулятор | HRB 3S LiPo Battery 11.1V 2200mAh 50C for RC Car with Deans Plug XT60 Connector For RC Car Helicopter Drone Boat Airplane |  |
| Преобразователь напряжения | TZT 1/5/10pcs LM2596 DC to DC Buck Converter 3.0-40V to 1.5-35V Power Supply Step Down Module |  |
| Основной блок управления SBC | Official Original Raspberry Pi 5 Cortex-A76 Linux 8GB Arm Board |  |
| Контроллер | Nano 3.0 Mini Type-C Micro USB With the bootloader compatible Nano controller for arduino CH340 USB driver 16Mhz ATMEGA328P |  |
| Лидар | Original LDS Lidar For Xiaomi Mijia STYTJ02YM Robot Vacuum Cleaner Accessory Replacement MVXVC01-JG Laser Distance Sensor Parts |  |
| Драйвер моторов | L298N Stepper DC Motor Driver |  |
| Мотор с энкодером | JGB37-520 encoder motor Smart car motor DC 12V small motor car kit speed motor |  |
| Камера | Raspberry Pi Camera Module 3 |  |
| Ультразвуковой датчик | 3.3V-5V/5V HC-SR04 HYSRF05 Ultrasonic Ranging Module Sensor |  |
| Основание | 3D печать ([3D модели](https://github.com/makarov-na/turtle-bot-3d-models)) |  |
| Основание шасси | 3D печать ([3D модели](https://github.com/makarov-na/turtle-bot-3d-models)) |  |
| Роликовое колесо | Self Adhesive Caster Mini Swivel Wheels Stainless Steel Universal Wheel 360 Degree Rotation Pulley for Furniture Trash Can |  |
| Колесо | Car Model 65MM Tyre Big Friction Wheel Toy Intelligent Car Robot Wheel Wheel DIY |  |
| Крепление мотора | 3D печать ([3D модели](https://github.com/makarov-na/turtle-bot-3d-models)) |  |
| Стойка 35mm,55m(35+20) | Solid Brass Copper M3 Hex Standoff Hexagon Pillar F-F Female-Female Spacer for PCB Board Motherboard |  |
Полный список компонентов со ссылками на магазины тут: [Список компонентов](../%D0%A1%D0%BF%D0%B8%D1%81%D0%BE%D0%BA%20%D0%BA%D0%BE%D0%BC%D0%BF%D0%BE%D0%BD%D0%B5%D0%BD%D1%82%D0%BE%D0%B2/%D0%A1%D0%BF%D0%B8%D1%81%D0%BE%D0%BA%20%D0%BA%D0%BE%D0%BC%D0%BF%D0%BE%D0%BD%D0%B5%D0%BD%D1%82%D0%BE%D0%B2.md)

Это позволяет создать черновую модель бота. В черновой модели не проработаны все детали:

* Отсутствуют крепления камеры, датчиков, аккумулятор и других компонентов
* Расположение компонентов приблизительное

При этом понятно, что все необходимые компоненты подходят по размерам и для них достаточно места.

Общий вид бота:



Вид спереди:



Вид сбоку:



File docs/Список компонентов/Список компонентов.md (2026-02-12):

| Компонент | Модель | Картинка | Ссылка на магазин |
|---|---|---|---|
| Одноплатный компьютер | Official Original Raspberry Pi 5 Cortex-A76 Linux 8GB Arm Board |  | https://sl.aliexpress.ru/p?key=bJa2G3l |
| Микрокотроллер | Nano 3.0 Mini Type-C Micro USB With the bootloader compatible Nano controller for arduino CH340 USB driver 16Mhz ATMEGA328P |  | https://sl.aliexpress.ru/p?key=7qa2GQt |
| Аккумулятор | HRB 3S LiPo Battery 11.1V 2200mAh 50C for RC Car with Deans Plug XT60 Connector For RC Car Helicopter Drone Boat Airplane |  | https://sl.aliexpress.ru/p?key=PbWzGiA |
| Мотор | JGB37-520 encoder motor Smart car motor DC 12V small motor car kit speed motor. 178 RPM |  | https://sl.aliexpress.ru/p?key=BIWzGd6 |
| Роликовое колесо | 4PCS Self Adhesive Caster Mini Swivel Wheels Stainless Steel Universal Wheel 360 Degree Rotation Pulley for Furniture Trash Can |  | https://sl.aliexpress.ru/p?key=5gWzGvm https://sl.aliexpress.ru/p?key=CBWzGED |
| Драйвер для моторов | L298N Stepper DC Motor Driver |  | https://sl.aliexpress.ru/p?key=2vWzGFS |
| Понижающий модуль | Cedar High Power DC-DC Buck Module 9-14V to 5V Step down Voltage Power Supply Regulator for Power Supply Module |  | https://ali.click/qha1xs |
| Стойки 35 мм | Solid Brass Copper M3 Hex Standoff Hexagon Pillar F-F Female-Female Spacer for PCB Board Motherboard |  | https://sl.aliexpress.ru/p?key=FALzGcQ |
| Стойки 20 мм | Solid Brass Copper M3 Hex Standoff Hexagon Pillar M-F Male-Female Spacer for PCB Board Motherboard |  | https://sl.aliexpress.ru/p?key=SbLzGcZ |
| Винты 8 мм | Cross Recessed Pan Head Screws M3 304 Stainless Steel Rounnd Phillips TV Machine Screw DIN7985 |  | https://sl.aliexpress.ru/p?key=h3LzGvg |
| Лидар | Original LDS Lidar For Xiaomi Mijia STYTJ02YM Robot Vacuum Cleaner Accessory Replacement MVXVC01-JG Laser Distance Sensor Parts |  | https://ali.click/cbhtn1 |
| Защита для аккумулятора | 1pcs or 4pcs Hot Sell 2s 2s 3s 4s 5s 6s 7s 8S 1-8S LED Low Voltage Buzzer Alarm Lipo Voltage Indicator Checker Tester Wholesale |  | https://ali.click/rgmko4 |
| Утразвуковой дальномер  | HY-SRF04 SRF04 Ultrasonic Distance Sensor Module 5Pin DC 5V For Arduino UNO Replace SR04 Electronic Brick Compatible Interface  |  | https://ali.click/u1ais1 |
| Камера | Pi Camera Module 3 |  | https://ali.click/osdisr |
| Зарядное устройство | IMAX B6AC 80W RC Balance Charger+ |  | https://ali.click/mjc1xj |
| Выключатель клавишный | KCD1 21*15mm ON-OFF Boat Car Rocker Switch |  | https://ali.click/rtz2xe |

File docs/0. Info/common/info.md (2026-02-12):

### Общая информация 

* https://github.com/robotis-git/turtlebot3
* https://emanual.robotis.com/docs/en/platform/turtlebot3/overview/

### Схожие проекты

* https://amperka.ru/blogs/projects/abot-robot-part-1****
* https://www.instructables.com/Build-Your-Own-Turtblebot-Robot/
* https://www.printables.com/model/707206-raspberry-pi-3b-cam-rover-with-arm

### 3D Модели

* Модели деталей и описание компонентов доступно тут: https://emanual.robotis.com/docs/en/platform/turtlebot3/features/#specifications
* После регистрации доступна выгрузка в stl https://cad.onshape.com/documents
* Порезать модель на части получилось в https://www.tinkercad.com/

* https://github.com/thedch/indoor-autonomous-system-cad
* https://grabcad.com/library/jgb37-520-12-v-metal-geared-motor-bracket-1

### Схемотехника для моторов

#### Полное описание 
* https://howtomechatronics.com/tutorials/arduino/arduino-dc-motor-control-tutorial-l298n-pwm-h-bridge/

#### Выжимка

Схема

Аккумулятор

I'd probably use a rechargeable 4S 14.8V Lipo battery for the motor. An L298N drops quite a lot of the supplied voltage so you need around 15V to have a reasonable chance of getting 12V at the motor.
The battery capacity (mAh) needed will depend on how long you expect the motors to run for. And you'll need a proper Lipo charger too.
There are many other options even a 12V lead-acid battery may work.

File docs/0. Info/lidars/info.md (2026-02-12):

Is LIDAR easy to use for hobbyists? DIY Roomba? Obstacle Avoidance System for Robotics
https://www.youtube.com/watch?v=_--8K1BW_O4

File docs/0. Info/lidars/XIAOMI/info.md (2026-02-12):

STYTJ02YM lidar

https://www.youtube.com/watch?v=S_xONJO4-Q0&t=2s

How to use a $20 laser distance sensor (from vacuum robots)
https://www.youtube.com/watch?v=mbxZAlJjE8A

https://www.youtube.com/shorts/WMxK5FvlEKs
https://www.youtube.com/watch?v=b5hEG3b_Kec



https://github.com/engineerm-jp/vacuum_robot_lidar

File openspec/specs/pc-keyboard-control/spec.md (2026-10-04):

# PC Keyboard Control

## Purpose
Консольное Python-приложение на ПК для управления роботом по Bluetooth: чтение стрелок в raw-режиме, дискретные инкременты ±10%, heartbeat 200 мс, graceful shutdown и автореконнект при обрыве линка.
## Requirements
### Requirement: Console app reads arrow keys without Enter

The application SHALL run a console (terminal) session in raw mode and SHALL recognize the arrow keys Up, Down, Left, Right, and the exit key `q`, reacting to a key press immediately without requiring the Enter key. Terminal contents and behavior SHALL be restored when the application exits.

#### Scenario: Arrow key press is detected immediately

- **WHEN** the user presses an arrow key while the application runs
- **THEN** the application reacts to that key press without waiting for Enter

#### Scenario: Exit key recognized

- **WHEN** the user presses `q` or sends Ctrl+C
- **THEN** the application shuts down and restores the terminal

### Requirement: Discrete speed increments

Starting from `set_speed(0, 0)`, each arrow key press SHALL change the held command by exactly 10% of the configured maximum: Up increments linear speed, Down decrements linear speed, Left increments angular speed, Right decrements angular speed. Linear and angular components SHALL be maintained independently (a forward-and-turn command keeps both components). Each component SHALL be capped so it never exceeds ±100% of its maximum, and Down beyond 0% SHALL continue into negative linear speed (reverse driving).

#### Scenario: Initial command is zero

- **WHEN** the application starts and connects
- **THEN** it sends `set_speed 0.0 0.0` as the initial command

#### Scenario: Linear increment

- **WHEN** the user presses Up once
- **THEN** the linear component becomes +10% of maximum and is sent as the new command

#### Scenario: Linear decrement into reverse

- **WHEN** the user presses Down while linear speed is at +10%
- **THEN** the linear component returns to 0%, and a further Down press drives into negative (reverse) territory

#### Scenario: Angular increment and decrement

- **WHEN** the user presses Left and then Right
- **THEN** the angular component first rises to +10% and then returns to 0% of the angular maximum

#### Scenario: Combined forward and turn

- **WHEN** the user presses Up followed by Left
- **THEN** the command keeps the linear increment and adds the angular increment, resulting in a turn while driving forward

#### Scenario: Cap at maximum

- **WHEN** the user presses Up ten times from zero
- **THEN** the linear component reaches +100% and additional Up presses do not raise it further

### Requirement: Command mapping matches firmware limits

The application SHALL treat +100% linear speed as `V_MAX_MM_S = 300` mm/s and +100% angular speed as `ω_max = 2·300/WHEELBASE_MM ≈ 3.24` rad/s, matching the constants defined in the firmware, and SHALL send numeric values to one decimal place for mm/s and two decimal places for rad/s.

#### Scenario: Ten percent step maps to firmware units

- **WHEN** the user presses Up once
- **THEN** the application sends `set_speed 30.0 0.0` (10% of 300 mm/s)

#### Scenario: Angular step maps to firmware units

- **WHEN** the user presses Left once
- **THEN** the application sends an angular value of approximately 0.32 rad/s (10% of ω_max)

### Requirement: Command repetition as heartbeat

While connected and running, the application SHALL resend the current command at a fixed interval of 200 ms, so the firmware watchdog (which stops the robot after a timeout) is reset, and so a host link drop is automatically detected on the firmware side.

#### Scenario: Steady heartbeat while idle

- **WHEN** the command is unchanged and the application is running
- **THEN** the current command is resent every 200 ms

#### Scenario: Heartbeat tone on each change

- **WHEN** the user changes the command with an arrow key
- **THEN** the new command is sent immediately and continues to be repeated every 200 ms

### Requirement: Graceful shutdown stops the robot

When the application exits, whether via `q`, Ctrl+C, or the reconnection attempts after a link loss being exhausted, it SHALL send a final `set_speed 0.0 0.0` before closing the connection so the robot does not continue moving with the last non-zero command.

#### Scenario: Quit via key sends stop

- **WHEN** the user presses `q`
- **THEN** the application sends `set_speed 0.0 0.0` and then closes the serial port

#### Scenario: Exit via Ctrl+C sends stop

- **WHEN** the user interrupts the application with Ctrl+C
- **THEN** the application sends `set_speed 0.0 0.0` and restores the terminal

#### Scenario: Exit after failed reconnect sends stop

- **WHEN** a link loss cannot be repaired within the reconnection attempts
- **THEN** the application sends `set_speed 0.0 0.0` and exits with an error message

### Requirement: Auto-reconnect on lost link

While running, if the connection to the robot is lost (for example a Bluetooth RFCOMM link that drops), the application SHALL automatically reconnect to the same port and resume sending the current command, keeping the current linear and angular components. It SHALL repeat the reconnection at most 5 times with a 0.5 s pause between attempts; if all attempts fail, the application SHALL exit per the graceful-shutdown requirement. A link loss SHALL not reset the user's held command.

#### Scenario: Link drop while driving resumes

- **WHEN** the connection drops while a non-zero command is held
- **THEN** the application reconnects and continues sending the same command without the user having to rebuild it from zero

#### Scenario: Unrecoverable link loss exits cleanly

- **WHEN** reconnection attempts all fail
- **THEN** the application prints a readable error message and exits with a final stop command

### Requirement: Incoming telemetry is drained while running

While connected, the application SHALL continuously read and discard incoming bytes from the serial port (the bot's keepalive acknowledgements). This keeps the terminal input buffer from filling up, which would otherwise stall the RFCOMM flow control and break the channel over time. Incoming acknowledgement lines SHALL additionally be parsed and rendered live in the telemetry dashboard (separate requirement below), so draining and displaying the data happen together.

#### Scenario: Acknowledgements are drained

- **WHEN** the bot sends `ack ...` lines every ~200 ms while the application is connected
- **THEN** the application reads them promptly so the input buffer does not grow without bound

#### Scenario: Acknowledgements are parsed for display

- **WHEN** a complete `ack` line with `mL/mR/oL/oR/iL/iR` fields arrives
- **THEN** the field values are parsed and pushed into the live telemetry dashboard, and the dashboard is redrawn

#### Scenario: Link closure mid-run is detected via read errors

- **WHEN** the channel closes while driving and a read or write on the port raises an I/O error (for example `EIO` on a dropped RFCOMM link)
- **THEN** the application treats it as a link loss and enters the auto-reconnect flow; an empty read on an idle tty (a no-op return with no data, which is normal on a `VMIN=0` port) is ignored and does not count as a closure

### Requirement: Status line shows absolute command values

The application SHALL display the current command with both the percentage of the maximum and the absolute value: linear speed in mm/s (one decimal place) and angular speed in rad/s (two decimal places), matching the format of the outgoing `set_speed` command.

#### Scenario: Linear value shown

- **WHEN** the linear component is +30%
- **THEN** the status line shows the percentage (`+30%`) together with the absolute value (`90.0 мм/с`)

#### Scenario: Angular value shown

- **WHEN** the angular component is -10%
- **THEN** the status line shows the percentage (`-10%`) together with the absolute value (`-0.32 рад/с`)

### Requirement: Live telemetry dashboard

While connected, the application SHALL run in a full-screen mode using the terminal alternate screen buffer and SHALL continuously render a telemetry dashboard: a status line on top, below it a table of the **50 most recent** acknowledgement lines (newest row on top), and a footer with control hints. The live dashboard SHALL be updated on each new acknowledgement (approximately every 200 ms). The most recent row SHALL be visually highlighted. All internal messages (connection status, link-loss notices, hints) SHALL be rendered inside the dashboard, not written over it. When the application exits, it SHALL leave the alternate screen buffer and restore the normal terminal screen.

#### Scenario: Dashboard shows last 50 acknowledgements with newest on top

- **WHEN** more than 50 acknowledgements have arrived
- **THEN** the table shows exactly the 50 most recent ones, with the newest row at the top of the table

#### Scenario: Latest row is highlighted

- **WHEN** the dashboard is drawn
- **THEN** the newest acknowledgement row is visually distinguished (inverted colors)

#### Scenario: Messages render inside the dashboard

- **WHEN** the application needs to notify the user (for example "link lost, reconnecting")
- **THEN** the message is displayed in a slot of the dashboard and the panel is re-rendered cleanly, without mixing with the live table

#### Scenario: Dashboard clears after reconnect

- **WHEN** the connection is re-established after a link loss
- **THEN** the telemetry table is cleared so stale values from the dead link are not shown alongside fresh ones

#### Scenario: Screen restored on exit

- **WHEN** the application exits via `q`, Ctrl+C, or exhausted reconnection attempts
- **THEN** the alternate screen buffer is left, the cursor visibility is restored, and the terminal shows the normal previous content

### Requirement: Serial port is supplied as a launch argument

The application SHALL accept the serial port device as its single command-line argument (for example `/dev/rfcomm0`) and SHALL connect at 9600 baud. If the port is missing or cannot be opened, the application SHALL print a clear error and exit.

#### Scenario: Port provided and opened

- **WHEN** the application is launched with a valid device path
- **THEN** it connects to the device at 9600 baud and starts sending commands

#### Scenario: Port missing

- **WHEN** the application is launched with no argument
- **THEN** it prints usage information and exits without an error trace

#### Scenario: Port cannot be opened

- **WHEN** the device path is invalid or the device is in use
- **THEN** the application prints a readable error message and exits

### Requirement: Space включает паузу

Приложение SHALL распознавать клавишу Space как переключатель паузы/продолжения во время работы. На первое нажатие Space приложение SHALL немедленно отправить `set_speed 0.0 0.0` и перейти в состояние паузы; на второе нажатие Space оно SHALL немедленно отправить хранимую команду и выйти из паузы. Нажатие Space без смены состояния паузы — холостой безвредный тумблер, в том числе когда хранимая команда уже нулевая.

#### Scenario: Первое нажатие ставит робота на паузу

- **WHEN** пользователь нажимает Space, пока удерживается ненулевая команда
- **THEN** приложение немедленно отправляет `set_speed 0.0 0.0`, а хранимая команда остаётся без изменений для будущего resume

#### Scenario: Второе нажатие продолжает движение

- **WHEN** пользователь повторно нажимает Space во время паузы
- **THEN** приложение немедленно отправляет хранимую команду и возобновляет обычный heartbeat

#### Scenario: Space при уже нулевой скорости безвреден

- **WHEN** пользователь нажимает Space, пока хранимая команда равна `0.0 0.0`
- **THEN** состояние паузы переключается без движения, и ошибок не возникает

### Requirement: Робот на паузе удерживается на месте

Во время паузы приложение SHALL продолжать повторять текущую отправляемую команду каждые 200 мс ровно так же, как heartbeat в рабочем цикле, фиксируя отправляемую команду равной `set_speed 0.0 0.0`, чтобы `power_stop()` прошивки постоянно перезапускался и робот оставался остановленным.

#### Scenario: Heartbeat продолжается во время паузы

- **WHEN** приложение на паузе и прошло 200 мс
- **THEN** оно снова отправляет `set_speed 0.0 0.0` вместо хранимой команды

### Requirement: Панель замораживается во время паузы

Во время паузы приложение SHALL NOT перерисовывать панель в ответ на входящие подтверждения или клавиши-стрелки: статусная строка и таблица из 50 строк телеметрии SHALL оставаться ровно такими, какими были в момент паузы. Входящие строки подтверждения SHALL по-прежнему читаться, парситься и помещаться в кольцо телеметрии, чтобы таблица сразу после resume показывала свежее состояние.

#### Scenario: Приход ack на паузе не перерисовывает панель

- **WHEN** во время паузы приходит строка `ack`
- **THEN** телеметрия парсится и сохраняется, но панель не перерисовывается

#### Scenario: Стрелки на паузе не перерисовывают панель

- **WHEN** пользователь нажимает стрелку во время паузы
- **THEN** команда не меняется, ничего не отправляется, и панель не перерисовывается

#### Scenario: Панель показывает свежую телеметрию на resume

- **WHEN** пользователь возобновляет движение, а в кольцо телеметрии за время паузы накопились подтверждения
- **THEN** панель перерисовывается на resume и показывает текущие строки подтверждений

### Requirement: Resume продолжает с прежней скорости

При выходе из состояния паузы хранимые линейная и угловая составляющие SHALL остаться без изменений с момента до паузы и SHALL быть немедленно отправлены как новая команда, продолжая прежнее движение без пересборки его пользователем с нуля.

#### Scenario: Хранимая скорость сохраняется через паузу

- **WHEN** пользователь ставит паузу на линейной +30% и угловой −10%, а затем возобновляет движение
- **THEN** приложение немедленно отправляет `set_speed 90.0 -0.32` (отображение хранимой команды)

### Requirement: Обрыв линка во время паузы оставляет робота на паузе

Если связь теряется во время паузы, приложение SHALL пройти существующий поток автореконнекта; при успешном переподключении робот SHALL оставаться на паузе и SHALL NOT возобновлять движение, пока пользователь не нажмёт Space. Хранимая команда SHALL пережить реконнект без изменений.

#### Scenario: Реконнект сохраняет состояние паузы

- **WHEN** линк обрывается во время паузы и успешно переподключается
- **THEN** робот остаётся остановленным, и движение возобновляется только по нажатию Space

#### Scenario: Хранимая команда переживает реконнект

- **WHEN** во время паузы произошли обрыв линка и реконнект
- **THEN** хранимая команда не изменилась и отправляется по Space, возобновляющему движение

### Requirement: Пауза не меняет поведение выхода

Во время паузы `q` и Ctrl+C SHALL по-прежнему корректно завершать приложение, и существующий финальный `set_speed 0.0 0.0` при graceful shutdown SHALL по-прежнему отправляться.

#### Scenario: Выход во время паузы останавливает робота

- **WHEN** пользователь нажимает `q` или Ctrl+C во время паузы
- **THEN** приложение отправляет финальную команду остановки и восстанавливает терминал

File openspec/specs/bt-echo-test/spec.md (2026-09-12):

# BT Echo Test

## Purpose

Отдельный тестовый скетч для проверки достоверности Bluetooth-канала (HC-06 / Hardware Serial D0/D1, 9600 бод): эхо-ответы с нарастающим счётчиком, однократное приветствие при старте, без задействования драйвера моторов и watchdog. Проверка канала выполняется консольными командами Linux (RFCOMM, RTT-замер, длительный тест на устойчивость).

## Requirements

### Requirement: Тестовый скетч принимает строки через Hardware Serial

Система SHALL предоставить отдельный скетч `src/motor_controller/bt_echo_test/bt_echo_test.ino`, который читает входящие строки с ПК по каналу Hardware Serial (D0/D1, на которые подключён HC-06) на скорости 9600 бод, накапливая символы до `\n` без блокирования `loop()`. Канал SHALL соответствовать ограничениям `bluetooth-telemetry`: D1 (TX) в HC-06 RXD через делитель (5V→3.3V), HC-06 TXD напрямую в D0, питание HC-06 от отдельного 5V.

#### Scenario: Приём строки целиком

- **WHEN** ПК отправляет строку, оканчивающуюся на `\n`, через HC-06
- **THEN** скетч распознаёт её и готов отвечать после закрывающего перевода строки

#### Scenario: Незавершённая строка не провоцирует ответа

- **WHEN** ПК отправляет текст без завершающего `\n`
- **THEN** скетч не отвечает, пока не придёт полная строка

### Requirement: Скетч возвращает строку с нарастающим счётчиком

Скетч SHALL отправлять обратно на ПК ответ вида `echo <n>: <line>\n`, где `<line>` — принятая строка без перевода строки, а `<n>` — нарастающий счётчик, увеличивающийся на 1 за каждый ответ. Так в потоке видна и корректность передачи, и потеря пакетов (пропуск счётчика).
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

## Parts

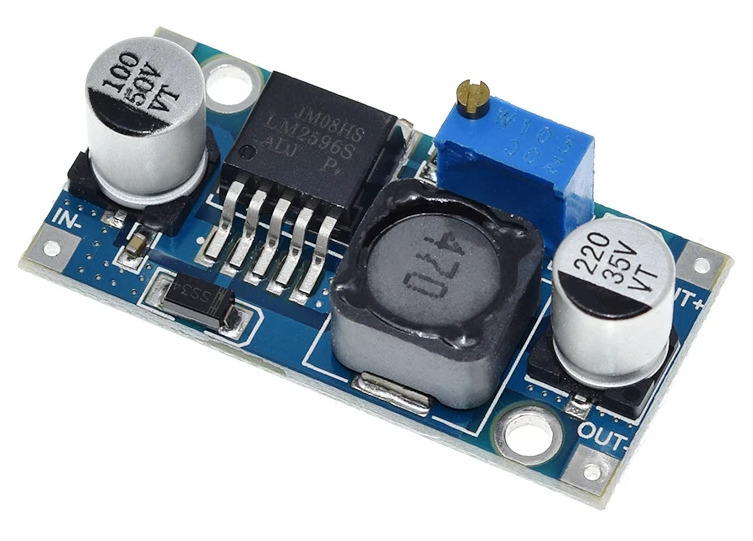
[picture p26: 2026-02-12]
docs/Список компонентов/components/dc_converter.jpg

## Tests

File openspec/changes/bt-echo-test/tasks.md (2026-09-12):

## 1. Тестовый скетч

- [x] 1.1 Создать `src/motor_controller/bt_echo_test/bt_echo_test.ino`: `Serial.begin(9600)` на Hardware Serial D0/D1, однократное приветствие `echo test ready` в `setup()`
- [x] 1.2 Накопление входящих символов в буфер до `\n` в `loop()` и ответ `echo <n>: <line>\n` с нарастающим счётчиком `n`
- [x] 1.3 Убедиться, что скетч не использует L298N (пины ШИМ и IN1-IN4 не активируются) и не имеет watchdog/периодических сообщений
- [x] 1.4 Скомпилировать скетч через `arduino-cli compile --fqbn arduino:avr:nano` без ошибок

## 2. Проверка канала консолью Linux

- [x] 2.1 Прошить `bt_echo_test.ino` в Arduino Nano
- [x] 2.2 L1 (ручной тест): `sudo rfcomm bind 0 00:21:13:00:0C:E3 1`, `sudo stty -F /dev/rfcomm0 raw -echo`, отправка `echo "ping" > /dev/rfcomm0` при работающем `cat` в фоне → в потоке появляется `echo 1: ping`
- [x] 2.3 L2 (RTT-loop): stdlib-скрипт Python шлёт пинги каждые 200 мс (50 шт.), фиксирует принятые ответы, RTT и любые потери/разрывы
- [x] 2.4 L3 (устойчивость): непрерывные пинги ≥60 с с фиксацией момента первого обрыва; записать, дожил ли поток до конца
- [ ] 2.5 Прошить обновлённый боевой `motor_controller.ino` (с keepalive-`ack`, реализован в `bt-keyboard-control`) и зафиксировать результаты L1–L3

## 3. Итоги

- [x] 3.1 Сопоставить результат L3 с гипотезой «двунаправленный keepalive удерживает линк» и определить следующий шаг (авт фикс боевого канала через ack-телеметрию либо диагностика железа смартфоном/btmon)

## Результаты проверки (L1–L3)

| Тест | Результат | Данные |
|---|---|---|
| L1 ручной эхо | PASS | ответ бота `echo 368: L1 manual` |
| L2 RTT-loop (50 пингов, 200 мс) | PASS | 49/50 принято, RTT средн. 224 мс, разрыва нет |
| L3 устойчивость (60 с) | PASS | 263/264 принято, RTT средн. 64 мс, первый обрыв: нет, линк прожил ≥60 с |

Вывод: при непрерывном **двунаправленном** трафике (пинги 200 мс + ответы бота) RFCOMM-линк HC-06 стабильно живёт ≥60 с против гарантированного обрыва ~5.2 с при одностороннем/тихом трафике. Гипотеза «двунаправленный keepalive удерживает линк» подтверждена. Следующий шаг: в боевой `bt-keyboard-control` добавить короткую периодическую телеметрию бот→ПК (~200 мс), что устранит обрывы управляющего канала.

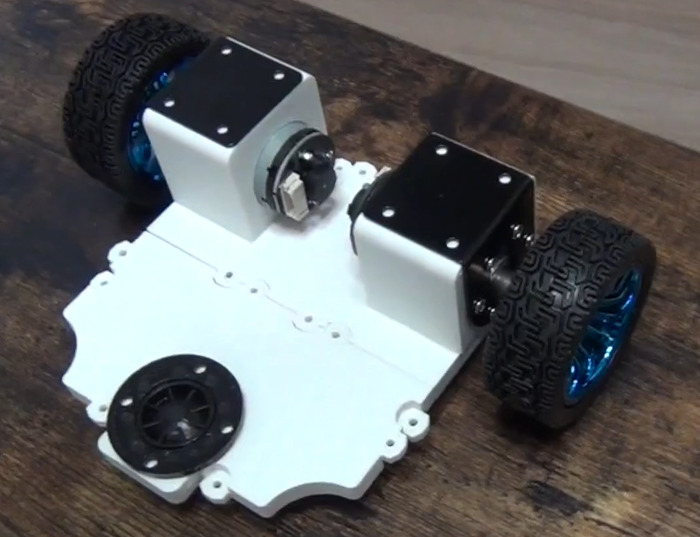
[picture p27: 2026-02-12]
docs/2. Шасси/media/result.jpg

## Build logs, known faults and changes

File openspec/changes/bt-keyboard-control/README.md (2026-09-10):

# bt-keyboard-control

Управление ботом с ПК по Bluetooth (HC-06): Python-консоль со стрелками + разбор команд в скетче + watchdog

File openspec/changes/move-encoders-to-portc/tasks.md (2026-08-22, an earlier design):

## 1. Перенос пинов энкодеров

- [x] 1.1 Заменить `PIN_ENC_R_A 8` на `PIN_ENC_R_A A0`
- [x] 1.2 Заменить `PIN_ENC_R_B 9` на `PIN_ENC_R_B A1`
- [x] 1.3 Заменить `PIN_ENC_L_A 10` на `PIN_ENC_L_A A2`
- [x] 1.4 Заменить `PIN_ENC_L_B 11` на `PIN_ENC_L_B A3`

## 2. Восстановление ISR

- [x] 2.1 Раскомментировать ISR(PCINT0_vect) и заменить на ISR(PCINT1_vect)
- [x] 2.2 Заменить чтение `PINB` на `PINC` в ISR
- [x] 2.3 Раскомментировать настройку PCICR/PCMSK и заменить на PCIE1/PCMSK1
- [x] 2.4 Заменить маску прерываний: `PCINT0|PCINT1|PCINT2|PCINT3` на `PCINT8|PCINT9|PCINT10|PCINT11`

## 3. Физическая перепайка (hardware)

- [ ] 3.1 Перепаять провод Right encoder A: D8 → A0
- [ ] 3.2 Перепаять провод Right encoder B: D9 → A1
- [ ] 3.3 Перепаять провод Left encoder A: D10 → A2
- [ ] 3.4 Перепаять провод Left encoder B: D11 → A3

## 4. Обновление документации

- [x] 4.1 Обновить таблицу распиновки в `docs/4. Блок управления приводом/Блок управления приводом.md`: D8→A0, D9→A1, D10→A2, D11→A3; D12/D13 → HC-06; A4-A7 → FREE

## 5. Проверка

- [ ] 5.1 Убедиться, что код компилируется без ошибок
- [ ] 5.2 Убедиться, что HC-06 продолжает работать (D12/D13 не задеты)
- [ ] 5.3 Проверить, что энкодеры считывают тики при вращении моторов

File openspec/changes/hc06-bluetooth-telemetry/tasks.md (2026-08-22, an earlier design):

## 1. Setup — SoftwareSerial

- [x] 1.1 Добавить `#include <SoftwareSerial.h>` в motor_controller.ino
- [x] 1.2 Определить пины: `PIN_BT_RX 12`, `PIN_BT_TX 13`
- [x] 1.3 Определить скорость: `BT_BAUD 9600`
- [x] 1.4 Создать объект SoftwareSerial: `SoftwareSerial btSerial(PIN_BT_RX, PIN_BT_TX);`

## 2. Инициализация в setup()

- [x] 2.1 Добавить `btSerial.begin(BT_BAUD);` в setup() после существующего кода
- [x] 2.2 Добавить начальное сообщение `btSerial.println("hello PC from ARDU");` в setup() для проверки связи при старте

## 3. Периодическая отправка в loop()

- [x] 3.1 Добавить переменную `lastBtSendMs` для отслеживания времени последней отправки
- [x] 3.2 Добавить блок в loop(): каждую 1 секунду отправлять `"hello PC from ARDU"` через btSerial.println()
- [x] 3.3 Убедиться, что отправка не блокирует основной цикл (non-blocking, через millis())

## 4. Проверка — существующий код не сломан

- [x] 4.1 Убедиться, что D12/D13 не используются в другом коде firmware
- [x] 4.2 Убедиться, что Hardware Serial (D0/D1) не задействован новым кодом
- [x] 4.3 Проверить, что PCINT прерывания на D8-D11 не конфликтуют с SoftwareSerial

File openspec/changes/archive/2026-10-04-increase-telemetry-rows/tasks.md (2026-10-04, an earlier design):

## 1. Код пульта

- [x] 1.1 В `src/motor_controller/motor_controller/controller.py` поднять `TELEMETRY_LINES` с 20 до 50 (строка 67). Логику рендера, `parse_ack`, форматтеры и обрезку по ширине не трогать — они уже параметризованы этой константой.
- [x] 1.2 В docstring модуля (строка 20) заменить «живая таблица последних 20 ack-ответов» на «последних 50 ack-ответов».
- [x] 1.3 Убедиться, что в docstring и в комментариях не осталось других упоминаний числа 20 как размера таблицы.

## 2. Документация

- [x] 2.1 В `docs/4. Блок управления приводом/Блок управления приводом.md:137` заменить «последние 20 строк `ack`» на «последние 50 строк `ack`».
- [x] 2.2 В том же файле (раздел `## Черновик`, строка 142) снять пункт «Увеличить количество строк с телеметрией в консоли управления» как выполненный. Пункт про полный лог телеметрии в файл оставить — он этим change'ом не решается.

## 3. Проверка без железа

- [x] 3.1 Импортировать `controller.py` и отрисовать панель через `render_panel` при 50 заполненных строках данных: результат — ровно 55 строк, из них 50 строк данных и 5 служебных.
- [x] 3.2 Проверить стабильность высоты: при 0, 1, 49 и 50 строках данных высота панели остаётся 55.
- [x] 3.3 Проверить, что инверсия (`\x1b[7m`) присутствует ровно в одной строке таблицы — на самой свежей, и нигде больше.
- [x] 3.4 Проверить обрезку по ширине при `cols` = 60, 80 и 120: строки не переносятся, обрезка работает как раньше.
- [x] 3.5 Проверить, что `TelemetryRing()` без аргументов удерживает 50 элементов: после 120 `push()` в кольце остаётся 50, `items()[0]` — самая свежая запись.

  Прогнан скриптом `/tmp/opencode/check_rows.py` (44 проверки, все зелёные). Скрипт лежит вне репозитория — автотестов в проекте нет, см. 6.2. Дополнительно проверено, что функции, которые задача 1.1 просила не трогать (`parse_ack`, `format_row`, `crop`, `invert_line`, `_ACK_RE`, `Ack` и др.), совпадают с git HEAD побайтово по коду функций; изменилась только константа.

## 4. Ручная проверка на железе

Бот подключён: `/dev/rfcomm0` привязан к HC-06 (`00:21:13:00:0C:E3`, channel 1), спарен и bonded. Пульт запускался против настоящего бота (`/tmp/opencode/real_bot.py`) в окне 70×80.

- [x] 4.1 Запустить `controller.py /dev/rfcomm0` в окне из 70 строк: панель занимает 55 строк, терминал не прокручивается, 15 строк внизу свободны.

  Проверено на живом боте: пульт поднялся на `/dev/rfcomm0`, пошли настоящие `ack` (n 233…184 — 50 подряд, по 5 в секунду при heartbeat 200 мс), каждый кадр содержит ровно 55 строк. Так как 55 < 70, панель помещается и терминал не прокручивается; свободны 70 − 55 = 15 строк.
- [x] 4.2 Убедиться, что видны строка статуса и заголовок колонок (при 20 строках в окне 24 они уезжали за верхний край — проверить, что теперь в большом окне всё на месте).

  Проверено на живом боте при окне 70×80: статус-строка на idx 0 (`lin +0% (+0 мм/с)  ang +0% (+0.00 рад/с)`), заголовок колонок на idx 2, футер последней строкой — в каждом из 55 кадров. Раньше при 20 строках таблицы в окне 24 панель была 25 строк и статус уезжал; теперь при 50 строках в окне 70 за верхний край не уезжает ничего.
- [x] 4.3 Дать боту проехать несколько манёвров подряд и убедиться, что таблица показывает предыдущие манёвры, а не только текущий.

  Проверено на живом боте (`/tmp/opencode/real_bot.py --drive`, с разрешения на движение): три фазы подряд — вперёд, вперёд, разворот влево.

  Главное наблюдение — в одном кадре одновременно видны **разные** манёвры: четыре разных уставки линейной скорости, переходы расположены на строках 37, 38 и 39 сверху (`v=180.0` — текущий, строки 1–36; `v=150.0` — 37; `v=120.0` — 38; `v=90.0` — 39 и ниже). То есть предыдущие уставки не вытесняются текущей, как было бы при 20 строках: там 4 секунды истории, и переходы ушли бы за верхний край.

  Энкодеры при движении читаются: `mL` в таблице принимает 19 различных значений (0.0 … 153.8), то есть строки — не нули, а реальные измерения. Это же подтверждает, что заявленная в `docs/4. Блок управления приводом` особенность («на стопе измеренная скорость замирает») при движении не мешает.

  Выход по `q` после манёвров: код 0, alternate screen покинут, курсор возвращён. В скрипт добавлена страховка `panic_stop` через `atexit` — при любом исключении она отправляет `q` (пульт перед выходом шлёт `set_speed 0.0 0.0`) и добивает процесс, чтобы бот не остался едущим. После прогона процессов пульта нет, `rfcomm0` вернулся в `channel 1 closed`.
- [x] 4.4 Нажать Space: панель замирает, таблица из 50 строк остаётся на месте; дождаться прихода `ack` и убедиться, что перерисовки нет. После повторного Space панель показывает свежую телеметрию.

  Проверено и на живом боте: Space даёт немедленный стоп, при продолжающихся `ack` число кадров не меняется (55 → 55 за 2 с), повторный Space перерисовку возвращает (55 → 64). Ранее то же подтверждено в PTY: на паузе heartbeat продолжается и все команды нулевые, робот удерживается на месте.
- [x] 4.5 Нажать `q`: бот получает финальный `set_speed 0.0 0.0`, alternate screen покидается, содержимое терминала восстановлено.

  Проверено и на живом боте: по `q` процесс завершается с кодом 0, вывод содержит `ESC[?1049l` (выход из alternate screen) и `ESC[?25h` (возврат курсора). Финальный `set_speed 0.0 0.0` подтверждён в PTY-прогоне чтением команд с порта.

## 5. Валидация

- [x] 5.1 `openspec validate --all` — убедиться, что дельта `pc-keyboard-control` проходит валидацию и требуемые разделы не потеряны при слиянии.

  `openspec validate increase-telemetry-rows` → `Change 'increase-telemetry-rows' is valid`. Потеря детали при слиянии проверена явно: текст обоих требований в дельте отличается от основной спеки только числом строк (20 → 50), ни одно предложение не потеряно и ни одно не добавлено. Сценарии: у `Live telemetry dashboard` в основной спеке 5, в дельте те же 5; у `Панель замораживается во время паузы` 3 и в основной спеке, и в дельте — все на месте.
- [x] 5.2 Отдельно отметить, что `spec/encoder-test-sketch` падает до и после этого change'а: его `spec.md` содержит delta-заголовок `## ADDED Requirements` вместо `## Purpose` / `## Requirements`. Это предсуществующий дефект архивации `2026-09-10-add-encoder-test-sketch`, к этому change'у не относится и здесь не чинится.

  Подтверждено: `openspec validate --all` → `Totals: 8 passed, 1 failed (9 items)`, единственный провал — `spec/encoder-test-sketch` с ошибкой `Spec must have a Purpose section`. Файл начинается с `## ADDED Requirements` (то есть дельта была архивирована как основная спека). Последний коммит, трогавший этот файл, — `5e946b4`, к этому change'у отношения не имеет; `git diff` по нему пуст.
- [x] 5.3 Перед архивацией снять решение, отдельным change'ом ли нет, чинить ли `spec/encoder-test-sketch`, чтобы `openspec validate --all` был зелёным.

  Решение: **не чинить**. Дефект предсуществующий и к этому change'у не относится; `openspec validate --all` остаётся с одним падением (`8 passed, 1 failed`) — это ожидаемое состояние репозитория, а не регрессия. Отдельный change на починку не заводился.

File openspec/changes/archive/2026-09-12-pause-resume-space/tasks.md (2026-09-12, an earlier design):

## 1. Состояние и heartbeat

- [x] 1.1 Добавить флаг `paused` в словарь `state` в `controller.py` и константу клавиши `SPACE` (`b" "`)
- [x] 1.2 Разделить хранимую и отправляемую скорость: heartbeat шлёт отправляемые значения — `(0, 0)` на паузе и хранимую команду иначе
- [x] 1.3 Вынести хелпер, вычисляющий пару отправляемых значений из состояния, и добавить модульные тесты, проверяющие, что в паузе пара равна `(0, 0)`

## 2. Обработка переключателя паузы

- [x] 2.1 Обработать Space в `run()`: переключить `paused`, на паузу сразу отправить `set_speed 0.0 0.0` и прекратить перерисовки по ack/стрелкам
- [x] 2.2 На resume сразу отправить хранимую команду, вернуть вывод heartbeat и перерисовать панель (показывается накопленная свежая телеметрия)
- [x] 2.3 Игнорировать стрелки на паузе: без изменения хранимой скорости, без отправки, без перерисовки; путь выхода `q`/Ctrl+C не менять

## 3. Перерисовка с учётом паузы

- [x] 3.1 Подавить перерисовку панели по новым ack на паузе, продолжая парсить их и класть в кольцо
- [x] 3.2 Убедиться, что явные переходы (подключение, обрыв линка, переподключение, resume) всё ещё рисуются на паузе и что реконнект после обрыва оставляет робота на паузе с нетронутой хранимой командой

## 4. Тесты

- [x] 4.1 Добавить модульные тесты хелпера отправляемой команды: в паузе — ноль, на resume — хранимое отображение (например `+30%/−10% → set_speed 90.0 -0.32`)
- [x] 4.2 Добавить интеграционные тесты с фейковым serial-fd: последовательность Space (пауза → нулевой heartbeat → resume → хранимая команда), неактивность стрелок на паузе, отсутствие перерисовки по ack на паузе, сохранение паузы при реконнекте

## 5. Проверка на полу

- [x] 5.1 Прогнать полный набор тестов пульта (модульные + интеграционные) и убедиться, что всё зелёное
- [x] 5.2 Ручной смоук-тест на роботе: пауза удерживает робота, панель заморожена, resume продолжает с прежней скорости

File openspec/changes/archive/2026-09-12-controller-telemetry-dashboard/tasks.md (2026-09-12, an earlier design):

# Tasks: Телеметрическая панель в консольном пульте

Tasks break down implementation. PTY-тесты controller.py живут вне репозитория
(`/tmp/opencode/test_controller.py`) и юнит-тесты (`/tmp/opencode/test_controller_units.py`)
— сидят на изменениях run()/рендера.

## 1. Парсинг и хранилище телеметрии

- [x] 1.1 Добавить `parse_ack(line) -> Ack|None`: из строки `ack <n> <v> <w> mL=.. mR=.. oL=.. oR=.. iL=.. iR=..` извлекать float/int поля; невалидные строки → `None`
- [x] 1.2 Добавить `Ack` (dataclass) и кольцевой буфер `TelemetryRing` (`deque(maxlen=20)`) с методом `push(ack)` и `clear()`
- [x] 1.3 Юнит-тест парсера/кольца: валидная строка, битые поля, >20 значений удерживают последние 20, `clear()`

## 2. Рендерер панели (ANSI)

- [x] 2.1 Чистая функция `format_row(ack) -> str`: фиксированные колонки `# v w mL mR oL oR iL iR` (обрезка/дополнение до ширины экрана — отдельно в `crop()` на уровне `render_panel`)
- [x] 2.2 Чистая функция сборки панели `render_panel(status, rows, footer, cols) -> str`: статус, заголовок, 20 строк (свежие сверху), футер; обрезка до `cols`; инверсия последней строки (`\x1b[7m…\x1b[0m`, до инверсии строка кропается, чтобы `\x1b[0m` не терялся на узких экранах)
- [x] 2.3 Юнит-тест рендера: новые сверху, обрезка ширины, инверсия только последней строки

## 3. Терминальные переходы и интеграция в controller.py

- [x] 3.1 Вход в панель: `\x1b[?1049h` + `\x1b[?25l`; выход: `\x1b[?25h` + `\x1b[?1049l` в `finally`/`atexit` рядом с восстановлением termios
- [x] 3.2 Перевести `out()`-сообщения (подключение, «Связь потеряна», подсказки) в слоты панели: статус-строка/футер; убрать прямые `print` из интерактивного цикла (`out()` удалён, `print` не используется)
- [x] 3.3 В `run()`: накапливать входящие байты в буфер до `\n` (rfcomm режет строки), полные строки → `parse_ack` → `TelemetryRing.push`; рендер после пачки новых ack; ограничение буфера `MAX_RX_BUFFER = 512`
- [x] 3.4 При успешном переподключении — `TelemetryRing.clear()` и перерисовка панели
- [x] 3.5 Статусная строка с абсолютными значениями: `lin +30% (90.0 мм/с)  ang -10% (-0.32 рад/с)`
- [x] 3.6 Ширина экрана перед рендером через `shutil.get_terminal_size()` (stdout) с fallback 80 при `winsize == 0`; без привязки к `SIGWINCH`

## 4. Проверка

- [x] 4.1 PTY-тесты controller.py остаются зелёными с новой панелью (28/28: старые сценарии + панель)
- [x] 4.2 Новый PTY-контрпример: приход 25 ack → в последнем кадре ровно 20 строк, `25..6` сверху вниз, вытесненный #1 отсутствует, свежайшая строка инвертирована; после `q` экран восстановлен (`\x1b[?1049l` в выводе)
- [x] 4.3 На железе (`controller.py /dev/rfcomm0`): панель обновляется на ходу, значения совпадают с телеметрией; реконнект чистит буфер; после `q` терминал в норме (проверено пользователем)

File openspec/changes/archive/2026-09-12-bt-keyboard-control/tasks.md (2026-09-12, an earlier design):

## 1. Прошивка: приём команд

- [x] 1.1 Убрать из `motor_controller.ino` демо-режим в `loop()` (auto-`set_speed(TEST_SPEED_MM_S, 0)`, `power_stop()` через `TEST_RUN_TIME_MS`) и константы `TEST_SPEED_MM_S`, `TEST_RUN_TIME_MS`
- [x] 1.2 Убрать периодическую отправку «hello PC from ARDU» из `loop()`; оставить однократное приветствие в `setup()`
- [x] 1.3 Добавить накопление строки из `Serial.read()` до `\n` (буфер, без блокирования `loop()`)
- [x] 1.4 Разбор строки через ручной парсер: токенизация `strtok_r` + `strtod` с валидацией обоих чисел до конца строки (невалидные игнорируются). Пришло на смену `sscanf %f`: дефолтный scanf_min avr-libc не поддерживает `%f` — бот молча игнорировал все команды (см. design «Risks», найдено на железе)
- [x] 1.5 При успешном разборе сбросить watchdog-таймер и применить команду: `set_speed(v, w)` для ненулевой результирующей скорости либо `power_stop()` при (|v|<0.05 и |w|<0.05). Нулевая команда тормозит и сбрасывает ПИД-интеграл: без этого antij integral windup после разгона оставляет бота едущим ~27 мм/с (механика: Kp·(0−measured)+Ki·I=0 ⇒ measured=(Ki/Kp)·I_limit≈27 для I_limit=200); найдено на железе как «Down → 0%, но бот продолжает ехать»
- [x] 1.6 Добавить watchdog: `lastCommandMs`; если `now - lastCommandMs > WATCHDOG_TIMEOUT_MS` → `stop()`, watchdog активен сразу после boot (стартовое значение таймера 0 → stop, пока не пришла команда)
- [x] 1.7 Проверить сборку скетча и поведение через USB Serial Monitor: `set_speed 30.0 0.0` движет ботом, тишина >1 с останавливает. Проверено по RFCOMM (тот же Hardware Serial D0/D1): движение, стоп `power_stop`, watchdog

## 1a. Диагностика движения (закрыта — причина найдена на железе)

- [x] 1a.1 Наблюдения: `set_speed 0.0` не останавливает бот; `set_speed -30.0` не едет назад; колеса идут неравномерно (замедление/ускорение). Гипотеза windup объясняет только первый симптом — нужны данные контура
- [x] 1a.2 Добавить диагностическую телеметрию в ack: `mL/mR`, `oL/oR`, `iL/iR` (измеренная скорость, ШИМ-выход, интеграл каждого колеса), собрать 8174 B / 26%; PTY-тесты controller.py 15/15 PASS
- [x] 1a.3 По телеметрии установить причину и зафиксировать исправление в контуре — см. 1a.4–1a.6
- [x] 1a.4 **Знак обратной связи инвертирован.** После переноса энкодеров на Port C (A0–A3) каналы A/B на обоих колёсах поменялись местами → счёт и measured имеют неверный знак. Вращение колеса вперёд руками давало `mL=mR≈-495`, а моторы уходили в o=255 в ту же сторону (положительная обратная связь): «самораскрутка», «не тормозит», «не едет назад». Фикс: инверсия всей `QUAD_TABLE` (эквивалент swap A/B); `motorSign` и направление моторов не тронуты. Проверка руками: левое вперёд → `mL>0`, oL уходит в −122 (тормоз против руки); правое → `mR>0`, oR до −135
- [x] 1a.5 **Недостаточный запас усилия привода.** Порог трогания редуктора (56:1) ~55–65 ШИМ; при лимите интеграла 200 контур мог выдать максимум Kp·30+Ki·200=85 PWM — целевые 30 не достигались, баг «звук есть, нет движения». Фикс: `PID_INTEGRAL_LIMIT 200→500` и feedforward `PID_FF=255.0f/V_MAX_MM_S≈0.85`; `out = FF·setpoint + Kp·error + Ki·integral + Kd·deriv`. Собрано 8226 B / 26%
- [x] 1a.6 **Рывок/самораскрутка после паузы.** После долгой остановки `controlLoop` не работал, и при возобновлении `dt` и `prevTicks` были устаревшими: `dt`≈полной длительности паузы → гигантский фейковый вклад интеграла (наблюдались `iL=±296` и мотор, крутящийся несколько секунд). Фикс: в `controlLoop()` при `gap>200мс` сброс `prevTicks=ticks` и `gap=10мс`. Проверка на полу: возобновление после паузы 2 с → `iL≈4.5` без скачка, заем поворот чистый. Собрано 8336 B / 27%
- [x] 1a.7 Прогон на полу (прошивка с 1a.4–1a.6): FWD 50 → measured 25–42, стоп `power_stop`, FWD снова без рывка, НАЗАД −50 → measured −25…−42 — все три исходных симптома устранены

## 2. Python-приложение controller.py

- [x] 2.1 Создать `src/motor_controller/motor_controller/controller.py`: argparse для пути порта, открытие серийника через `serial.Serial`/`os.open` на 9600 бод; печать понятной ошибки при неуспехе
- [x] 2.2 Константы лимитов: `V_MAX_MM_S = 300.0`, `WHEELBASE_MM = 185.0`, `OMEGA_MAX_RAD_S = 2·V_MAX/WHEELBASE` со ссылкой-маяком на прошивку
- [x] 2.3 Состояние команд: `linear_pct`, `angular_pct`, стартовое `(0, 0)`; маппинг в `set_speed(linear_mm_s, omega_rad_s)`: линейная 1 знак после запятой, угловая 2
- [x] 2.4 Обработка стрелок: Up/Down ±10% linear (кламп ±100), Left/Right ±10% angular (кламп ±100), независимо, `q` = выход; печать текущих значений в консоль
- [x] 2.5 Raw-режим терминала: `termios`/`tty` перед чтением, восстановление в `finally`/`atexit`; неблокирующее чтение escape-последовательностей (`\x1b[A`–`\x1b[D`, вариант `\x1bOA`–`\x1bOD`)
- [x] 2.6 Heartbeat: повтор текущей команды каждые 200 мс (цикл с `select.select` на stdin с таймаутом)
- [x] 2.7 Корректный выход: при `q` и Ctrl+C отправить финальный `set_speed 0.0 0.0`, закрыть порт, восстановить терминал. Нюанс: в raw-режиме `ISIG` отключён, Ctrl+C приходит как байт `0x03`, а не SIGINT — добавлен в кнопки выхода (иначе из пульта было невозможно выйти)
- [x] 2.8 Автореконнект: при обрыве канала (OSError/EIO в середине работы) приложение 5 раз с паузой 0.5 с переоткрывает тот же порт и продолжает текущую команду без сброса `linear_pct`/`angular_pct`; при неудаче всех попыток — финальный stop и выход с ошибкой

## 3. Тест на реальном железе

- [x] 3.1 Прошить изменённый скетч, проверить watchdog через USB-монитор (движение → тишина → stop). Покрыто RFCOMM-проверками (движение → пауза → watchdog/стоп) на том же Serial; итоговый тест на полу пройден
- [x] 3.2 Запустить `controller.py` на USB-порту (не HC-06) и проверить все стрелки, инкременты, клампы, `q`, Ctrl+C. USB-вариант не обязателен: итоговый тест пройден по HC-06
- [x] 3.3 Спарить HC-06 с ПК, запустить `controller.py /dev/rfcomm0`, выполнить полный сценарий управления и проверить остановку при обрыве Bluetooth. Пройдено: пользователь подтвердил «управление работает»; остановка при обрыве — watchdog

## 4. Keepalive-телеметрия (устранение обрывов линка)

- [x] 4.1 Фичерм: отвечать `ack <n> <v> <w>` на каждую валидную `set_speed` (счётчик `cmdCounter` в `handleCommand`)
- [x] 4.2 controller.py: дренировать входящие ack-байты в `run()` через `select([sys.stdin, fd])`; пустой read на idle tty игнорируется, ошибки чтения/записи → `LinkLost`; состояние вынесено в изменяемый holder, переживает реконнект
- [x] 4.3 Скомпилировать прошивку (после замены scanf→strtok_r/strtod: 7606 B / 24%) и прогнать PTY-тесты controller.py (14/14 PASS, включая ack-поток во время управления)
- [x] 4.4 На железе: во время работы `controller.py` линк держится непрерывно (2+ минуты без обрывов), ack-поток не забивает канал. Пройдено: длительные сценарии управления по RFCOMM без падений линка

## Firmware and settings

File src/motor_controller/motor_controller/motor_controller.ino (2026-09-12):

// Блок управления приводом
// Arduino Nano + L298N + моторы с энкодерами
//
// Команды в теле робота:
//   set_speed(linear_speed, angular_speed)
//     linear_speed  — линейная скорость середины оси колёс, мм/с
//     angular_speed — угловая скорость, рад/с; + = против часовой (вид сверху)
//   stop()       — отключить драйвер, свободный выбег
//   power_stop() — силовое торможение (L298N fast motor stop)
//
// Подключение и направления моторов сверять с
// docs/4. Блок управления приводом/spec.md
//
// HC-06 Bluetooth: D0 (RX), D1 (TX), 9600 baud, Hardware Serial
//   HC-06 TX → D0 (напрямую, 3.3V читается как HIGH на 5V-логике)
//   HC-06 RX ← D1 (через делитель 5V → 3.3V, RX HC-06 не 5V-tolerant)
//   ВНИМАНИЕ: при перепрошивке через USB отключать HC-06 (загрузчик
//   использует D0/D1). SoftwareSerial не используется — его PCINT-алиасы
//   конфликтуют с ISR(PCINT1_vect) энкодеров на ATmega328P.
//
// Протокол управления по каналу (текст, \n — конец команды):
//   set_speed <linear_speed> <angular_speed>
//     linear_speed  — мм/с, любой знак
//     angular_speed — рад/с, любой знак
// Команды принимаются всегда. Watchdog: если команда не получена более
// WATCHDOG_TIMEOUT_MS, бот выполняет stop() до прихода новой команды.

#define PIN_IN1_R  2
#define PIN_IN2_R  3
#define PIN_ENA_R  5
#define PIN_ENC_R_A A0
#define PIN_ENC_R_B A1

#define PIN_IN3_L  4
#define PIN_IN4_L  7
#define PIN_ENB_L  6
#define PIN_ENC_L_A A2
#define PIN_ENC_L_B A3

#define BT_BAUD 9600

const float WHEEL_DIAMETER_MM = 67.0f;
const float WHEELBASE_MM = 185.0f;
const float V_MAX_MM_S = 300.0f;
const float OMEGA_MAX_RAD_S = 2.0f * V_MAX_MM_S / WHEELBASE_MM;

const uint32_t RAMP_DURATION_MS = 1000;
const uint32_t BRAKE_DURATION_MS = 300;
const uint32_t PID_PERIOD_MS = 10;
const uint16_t MIN_TICK_US = 50;
const uint32_t WATCHDOG_TIMEOUT_MS = 1000;

const uint16_t ENCODER_CPR  = 11;
const uint8_t  GEAR_RATIO   = 56;
const uint32_t TICKS_PER_WHEEL_REV = ENCODER_CPR * 4UL * GEAR_RATIO;

const float PID_KP = 1.5f;
const float PID_KI = 0.2f;
const float PID_KD = 0.0f;
const float PID_INTEGRAL_LIMIT = 500.0f;

// Прямая связь: компенсирует усилие, нужное мосту для поддержания скорости.
// Полная шкала ШИМ 255 ~= V_MAX мм/с, поэтому коэффициент 255/V_MAX≈0.85.
// Без неё на низких целях (напр. 30 мм/с) контур может выдать максимум
// Kp·30 + Ki·I_limit ≈ 45+40 = 85 ШИМ, а редуктор 56:1 трогается только
// c ~60 ШИМ — бот "жужжит" и не едет. FF добавляет ~0.85·setpoint сразу.
const float PID_FF = 255.0f / V_MAX_MM_S;

// Диагноз (контролируемый тест 2026-09-12): при вращении колеса "вперёд"
// руками оба энкодера показывали ОТРИЦАТЕЛЬНУЮ скорость (mL=mR=-4..-500
// мм/с) — контур работал в положительную обратную связь (моторы вылетали
// в oL=oR=255 в ту же сторону). motorSign(-1/+1) калиброваны под старую
// разводку D8-D11; после переезда на Port C (A0-A3) каналы A/B на обоих
// колёсах обменялись, что инвертирует подсчёт. Фикс: инвертировать таблицу
// (эквивалентно смене мест проводов A/B на обоих энкодерах) — это флипнет
// знак СЧЁТА, не тронув motorSign и направление моторов.
static const int8_t QUAD_TABLE[16] = {
    0, 1, -1, 0,
    -1, 0, 0, 1,
    1, 0, 0, -1,
    0, -1, 1, 0
};

enum WheelId { WHEEL_LEFT = 0, WHEEL_RIGHT = 1 };

enum DriveState { STATE_STOPPED, STATE_RUN, STATE_BRAKING };

struct Wheel {
  const uint8_t pinPwm;
  const uint8_t pinIn1;
  const uint8_t pinIn2;
  const int8_t motorSign;

  Wheel(uint8_t pwm, uint8_t in1, uint8_t in2, int8_t sign)
      : pinPwm(pwm), pinIn1(in1), pinIn2(in2), motorSign(sign) {}

  volatile int32_t ticks = 0;
  int32_t prevTicks = 0;

  float targetLinear = 0.0f;
  float rampedLinear = 0.0f;
  float measuredLinear = 0.0f;
  float rampFrom = 0.0f;
  uint32_t rampStartMs = 0;
  bool ramping = false;

  float integral = 0.0f;
  float prevError = 0.0f;
  float lastOut = 0.0f;

  void setTarget(float target) {
    rampFrom = rampedLinear;
    rampStartMs = millis();
    ramping = true;
    targetLinear = target;
  }

  void updateRamp(uint32_t now) {
    if (!ramping) {
      return;
    }
    float t = (float)(now - rampStartMs) / (float)RAMP_DURATION_MS;
    if (t >= 1.0f) {
      rampedLinear = targetLinear;
      ramping = false;
    } else {
      rampedLinear = rampFrom + (targetLinear - rampFrom) * t;
    }
  }

  void measureSpeed(float dtSec) {
    int32_t delta = ticks - prevTicks;
    prevTicks = ticks;
    float mmPerTick = PI * WHEEL_DIAMETER_MM / (float)TICKS_PER_WHEEL_REV;
    measuredLinear = (float)delta * mmPerTick * (float)motorSign / dtSec;
  }

  float pidUpdate(float setpoint, float feedback, float dt) {
    float error = setpoint - feedback;
    integral += error * dt;
    integral = constrain(integral, -PID_INTEGRAL_LIMIT, PID_INTEGRAL_LIMIT);
    float derivative = dt > 0.0f ? (error - prevError) / dt : 0.0f;
    prevError = error;
    float out = PID_FF * setpoint
              + PID_KP * error
              + PID_KI * integral
              + PID_KD * derivative;
    return constrain(out, -255.0f, 255.0f);
  }

  void resetPid() {
    integral = 0.0f;
    prevError = 0.0f;
  }

  void applyPwm(float pwmCmd) {
    bool robotForward = pwmCmd >= 0.0f;
    bool motorForward = (motorSign >= 0) ? robotForward : !robotForward;
    if (motorForward) {
      digitalWrite(pinIn1, LOW);
      digitalWrite(pinIn2, HIGH);
    } else {
      digitalWrite(pinIn1, HIGH);
      digitalWrite(pinIn2, LOW);
    }
    analogWrite(pinPwm, (int)constrain(fabsf(pwmCmd), 0.0f, 255.0f));
  }

  void brake() {
    digitalWrite(pinIn1, HIGH);
    digitalWrite(pinIn2, HIGH);
    analogWrite(pinPwm, 255);
  }

  void coast() {
    digitalWrite(pinIn1, LOW);
    digitalWrite(pinIn2, LOW);
    analogWrite(pinPwm, 0);
  }
};

Wheel wheels[2] = {
    {PIN_ENB_L, PIN_IN3_L, PIN_IN4_L, -1},
    {PIN_ENA_R, PIN_IN1_R, PIN_IN2_R, +1}
};

DriveState driveState = STATE_STOPPED;
uint32_t brakeStartMs = 0;
uint32_t lastControlMs = 0;

const uint8_t CMD_BUF_SIZE = 40;
char cmdBuf[CMD_BUF_SIZE];
uint8_t cmdLen = 0;
bool cmdOverflow = false;

uint32_t lastCommandMs = 0;
bool watchdogTripped = true;

uint32_t cmdCounter = 0;

static uint8_t prevEncState[2] = {0, 0};
static uint32_t lastTickMicros[2] = {0, 0};

void updateEncoder(int wheel, uint8_t state) {
  uint8_t idx = (prevEncState[wheel] << 2) | state;
  int8_t step = QUAD_TABLE[idx];
  if (step != 0) {
    prevEncState[wheel] = state;
    uint32_t now = micros();
    if (now - lastTickMicros[wheel] >= MIN_TICK_US) {
      lastTickMicros[wheel] = now;
      wheels[wheel].ticks += step;
    }
  }
}

ISR(PCINT1_vect) {
  uint8_t pins = PINC & 0x0F;
  updateEncoder(WHEEL_LEFT, (pins >> 2) & 0x03);
  updateEncoder(WHEEL_RIGHT, pins & 0x03);
}

void set_speed(float linearSpeed, float angularSpeed) {
  float vRight = linearSpeed + angularSpeed * WHEELBASE_MM / 2.0f;
  float vLeft = linearSpeed - angularSpeed * WHEELBASE_MM / 2.0f;

  float maxAbs = fmaxf(fabsf(vLeft), fabsf(vRight));
  if (maxAbs > V_MAX_MM_S) {
    float k = V_MAX_MM_S / maxAbs;
    vLeft *= k;
    vRight *= k;
  }

  driveState = STATE_RUN;
  wheels[WHEEL_LEFT].setTarget(vLeft);
  wheels[WHEEL_RIGHT].setTarget(vRight);
}

void stop() {
  driveState = STATE_STOPPED;
  wheels[WHEEL_LEFT].setTarget(0.0f);
  wheels[WHEEL_RIGHT].setTarget(0.0f);
  wheels[WHEEL_LEFT].coast();
  wheels[WHEEL_RIGHT].coast();
  wheels[WHEEL_LEFT].resetPid();
  wheels[WHEEL_RIGHT].resetPid();
}

void power_stop() {
  wheels[WHEEL_LEFT].setTarget(0.0f);
  wheels[WHEEL_RIGHT].setTarget(0.0f);
  wheels[WHEEL_LEFT].resetPid();
  wheels[WHEEL_RIGHT].resetPid();
  driveState = STATE_BRAKING;
  brakeStartMs = millis();
  wheels[WHEEL_LEFT].brake();
  wheels[WHEEL_RIGHT].brake();
}

void controlLoop() {
  uint32_t now = millis();
  uint32_t gap = now - lastControlMs;
  if (gap < PID_PERIOD_MS) {
    return;
  }
  // Если контур долго не работал (пауза, торможение, watchdog), первая
  // итерация после возобновления не должна "видеть" накопленное с тех пор:
  // иначе dt и дельта тиков дадут гигантский фейковый интеграл/скорость
  // (наблюдалось iL=±296 и "колёса сами крутятся после паузы"). Сбрасываем
  // точку отсчёта и берём штатные 10 мс.
  if (gap > 200UL) {
    for (int w = 0; w < 2; w++) {
      wheels[w].prevTicks = wheels[w].ticks;
    }
    gap = PID_PERIOD_MS;
  }
  float dt = (float)gap / 1000.0f;
  lastControlMs = now + (gap - PID_PERIOD_MS);

  for (int w = 0; w < 2; w++) {
    Wheel &wh = wheels[w];
    wh.updateRamp(now);
    wh.measureSpeed(dt);
    float out = wh.pidUpdate(wh.rampedLinear, wh.measuredLinear, dt);
    wh.lastOut = out;
    wh.applyPwm(out);
  }
}

void handleCommand(char *buf) {
  // Парсим вручную: scanf-вариант из avr-libc по умолчанию не умеет %f
  // (нужна принудительная линковка libscanf_flt), а strtof доступен всегда.
  char *saveptr = nullptr;
  char *tok = strtok_r(buf, " ", &saveptr);
  if (!tok || strcmp(tok, "set_speed") != 0) {
    return;
  }
  char *vTok = strtok_r(nullptr, " ", &saveptr);
  char *wTok = strtok_r(nullptr, " ", &saveptr);
  char *extra = strtok_r(nullptr, " ", &saveptr);
  if (!vTok || !wTok || extra != nullptr) {
    return;
  }
  char *endV = nullptr;
  char *endW = nullptr;
  float v = (float)strtod(vTok, &endV);
  float w = (float)strtod(wTok, &endW);
  if (endV == vTok || endW == wTok || *endV != '\0' || *endW != '\0') {
    return;
  }
  lastCommandMs = millis();
  watchdogTripped = false;
  if (fabsf(v) < 0.05f && fabsf(w) < 0.05f) {
    // 0-команда: резкая остановка + сброс ПИД. Без торможения integral
    // windup после разгона оставляет бота едущим ~ V_MAX*Ki/Kp·I_limit ≈
    // 27 мм/с: ошибка(0−measured)+Ki·I = 0 достигается при measured>0.
    power_stop();
  } else {
    set_speed(v, w);
  }

  // Keepalive-телеметрия: непрерывный двунаправленный трафик удерживает
  // RFCOMM-линк HC-06 (проверено: ≥60 с против обрыва ~5.2 с на
  // одностороннем трафике). Ответ на каждую команду создаёт его.
  cmdCounter++;
  Serial.print("ack ");
  Serial.print(cmdCounter);
  Serial.print(" ");
  Serial.print(v);
  Serial.print(" ");
  Serial.print(w);
  // Диагностика: измеренная скорость, выход ШИМ и интеграл каждого колеса.
  // mL/mR = measured, oL/oR = pid out, iL/iR = integral.
  Serial.print(" mL=");
  Serial.print(wheels[WHEEL_LEFT].measuredLinear);
  Serial.print(" mR=");
  Serial.print(wheels[WHEEL_RIGHT].measuredLinear);
  Serial.print(" oL=");
  Serial.print(wheels[WHEEL_LEFT].lastOut);
  Serial.print(" oR=");
  Serial.print(wheels[WHEEL_RIGHT].lastOut);
  Serial.print(" iL=");
  Serial.print(wheels[WHEEL_LEFT].integral);
  Serial.print(" iR=");
  Serial.print(wheels[WHEEL_RIGHT].integral);
  Serial.println();
}

void processSerial() {
  while (Serial.available() > 0) {
    char c = (char)Serial.read();
    if (c == '\n' || c == '\r') {
      if (cmdLen > 0 && !cmdOverflow) {
        cmdBuf[cmdLen] = '\0';
        handleCommand(cmdBuf);
        cmdLen = 0;
        cmdOverflow = false;
      }
    } else if (cmdLen < CMD_BUF_SIZE - 1) {
      cmdBuf[cmdLen++] = c;
    } else {
      cmdOverflow = true;
    }
  }
}

void setup() {
  pinMode(PIN_ENA_R, OUTPUT);
  pinMode(PIN_IN1_R, OUTPUT);
  pinMode(PIN_IN2_R, OUTPUT);
  pinMode(PIN_ENB_L, OUTPUT);
  pinMode(PIN_IN3_L, OUTPUT);
  pinMode(PIN_IN4_L, OUTPUT);

  pinMode(PIN_ENC_L_A, INPUT_PULLUP);
  pinMode(PIN_ENC_L_B, INPUT_PULLUP);
  pinMode(PIN_ENC_R_A, INPUT_PULLUP);
  pinMode(PIN_ENC_R_B, INPUT_PULLUP);

  wheels[WHEEL_LEFT].coast();
  wheels[WHEEL_RIGHT].coast();
  driveState = STATE_STOPPED;

  PCICR |= (1 << PCIE1);
  PCMSK1 |= (1 << PCINT8) | (1 << PCINT9) | (1 << PCINT10) | (1 << PCINT11);

  Serial.begin(BT_BAUD);
  Serial.println("hello PC from ARDU");
}

void loop() {
  uint32_t now = millis();

  if (driveState == STATE_BRAKING && now - brakeStartMs >= BRAKE_DURATION_MS) {
    driveState = STATE_STOPPED;
    wheels[WHEEL_LEFT].coast();
    wheels[WHEEL_RIGHT].coast();
  }

  if (driveState == STATE_RUN) {
    controlLoop();
  }

  processSerial();

  if (!watchdogTripped && now - lastCommandMs > WATCHDOG_TIMEOUT_MS) {
    watchdogTripped = true;
    stop();
  }
}

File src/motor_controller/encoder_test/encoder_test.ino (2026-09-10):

// Тестовый скетч проверки энкодеров
// Arduino Nano
//
// Читает квадратурные энкодеры обоих колёс через прерывания PORTC (A0-A3)
// и выводит значения тиков (со знаком) и скорость (мм/с) через Hardware Serial
// (D0/D1). HC-06 подключён на D0 (RX) и D1 (TX) — данные доступны и через
// Bluetooth, и через USB-монитор.
// Плюс в выводе = бот едет вперёд (правый мотор по часовой, левый против).
//
// Энкодерная логика скопирована из motor_controller.ino — при правках
// боевого скетча синхронизировать вручную.
//
// ВАЖНО: не используем SoftwareSerial (HC-06) — на ATmega328P она алиасит
// PCINT1_vect (и PCINT2_vect) на PCINT0_vect, что конфликтует с ISR(PCINT1_vect)
// энкодеров на этапе линковки (multiple definition of '__vector_4').
// Вывод идёт через встроенный Serial (D0/D1): HC-06 TX→D0, HC-06 RX←D1
// через делитель 5V→3.3V (HC-06 RX не 5V-tolerant).
//
// ВНИМАНИЕ: при перепрошивке отключать HC-06 (загрузчик Arduino использует D0/D1).
// Драйвер моторов (L298N) в этом скетче не задействуется.

#define PIN_ENC_R_A A0
#define PIN_ENC_R_B A1

#define PIN_ENC_L_A A2
#define PIN_ENC_L_B A3

#define HARDWARE_SERIAL_BAUD 9600

const float WHEEL_DIAMETER_MM = 67.0f;
const uint32_t SEND_PERIOD_MS = 1000;
const uint16_t MIN_TICK_US = 50;

const uint16_t ENCODER_CPR  = 11;
const uint8_t  GEAR_RATIO   = 56;
const uint32_t TICKS_PER_WHEEL_REV = ENCODER_CPR * 4UL * GEAR_RATIO;

static const int8_t QUAD_TABLE[16] = {
    0, -1, 1, 0,
    1, 0, 0, -1,
    -1, 0, 0, 1,
    0, 1, -1, 0
};

enum WheelId { WHEEL_LEFT = 0, WHEEL_RIGHT = 1 };

struct Wheel {
  const int8_t motorSign;

  volatile int32_t ticks = 0;
  int32_t prevTicks = 0;
  int32_t dispTicks = 0;
  float measuredLinear = 0.0f;

  Wheel(int8_t sign)
      : motorSign(sign) {}

  void measureSpeed(float dtSec) {
    int32_t delta = ticks - prevTicks;
    prevTicks = ticks;
    dispTicks = delta * motorSign;
    float mmPerTick = PI * WHEEL_DIAMETER_MM / (float)TICKS_PER_WHEEL_REV;
    measuredLinear = (float)delta * mmPerTick * (float)motorSign / dtSec;
  }
};

Wheel wheels[2] = {
    {-1},
    {+1}
};

uint32_t lastSendMs = 0;

static uint8_t prevEncState[2] = {0, 0};
static uint32_t lastTickMicros[2] = {0, 0};

void updateEncoder(int wheel, uint8_t state) {
  uint8_t idx = (prevEncState[wheel] << 2) | state;
  int8_t step = QUAD_TABLE[idx];
  if (step != 0) {
    prevEncState[wheel] = state;
    uint32_t now = micros();
    if (now - lastTickMicros[wheel] >= MIN_TICK_US) {
      lastTickMicros[wheel] = now;
      wheels[wheel].ticks += step;
    }
  }
}

ISR(PCINT1_vect) {
  uint8_t pins = PINC & 0x0F;
  updateEncoder(WHEEL_LEFT, (pins >> 2) & 0x03);
  updateEncoder(WHEEL_RIGHT, pins & 0x03);
}

void setup() {
  pinMode(PIN_ENC_L_A, INPUT_PULLUP);
  pinMode(PIN_ENC_L_B, INPUT_PULLUP);
  pinMode(PIN_ENC_R_A, INPUT_PULLUP);
  pinMode(PIN_ENC_R_B, INPUT_PULLUP);

  PCICR |= (1 << PCIE1);
  PCMSK1 |= (1 << PCINT8) | (1 << PCINT9) | (1 << PCINT10) | (1 << PCINT11);

  Serial.begin(HARDWARE_SERIAL_BAUD);
  Serial.println("encoder test ready");
}

void loop() {
  uint32_t now = millis();
  if (now - lastSendMs >= SEND_PERIOD_MS) {
    lastSendMs = now;
    float dt = (float)SEND_PERIOD_MS / 1000.0f;
    for (int w = 0; w < 2; w++) {
      wheels[w].measureSpeed(dt);
    }
    Serial.print("L:");
    Serial.print(wheels[WHEEL_LEFT].dispTicks);
    Serial.print(" R:");
    Serial.print(wheels[WHEEL_RIGHT].dispTicks);
    Serial.print(" Lmm/s:");
    Serial.print(wheels[WHEEL_LEFT].measuredLinear);
    Serial.print(" Rmm/s:");
    Serial.println(wheels[WHEEL_RIGHT].measuredLinear);
  }
}

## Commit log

2026-02-12 История урезана. Новый корень 16a41d5f1c17c3f597c481dae462ba6f017d2d66
    [motor-controller.kicad_sch]
2026-02-13 Перенес привод в раздел 4
    [motor-controller.kicad_sch]
2026-02-15 Исправлена ошибка
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2026-04-18 Исправлены опечатки Подправлен раздел про аккумулятор
2026-04-18 Исправлены опечатки
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2026-08-02 Реализован метод speed. Бот едет почти прямо.
    [motor-controller.kicad_sch]
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2026-08-22 Реализация без проеверок. Proposal для устранения конфликта по прерыванию между серийным портом и энкодеарами
2026-09-06 Энкодеры перенесены на отдельный порт с аппаратным прерыванием
    [motor-controller.kicad_sch]
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2026-09-10 Полностью исправлена проблема с конфликтом прерываний. Работает отправка Hello на PC
    [motor_controller.ino]
2026-09-12 Работает управление ботом по каналу, но есть проблемы - не все команды проходят
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2026-09-12 Стабильное управление по HC-06: фикс знака энкодеров, усилие привода, рывок после паузы
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2026-09-12 Пауза на Space: быстрая остановка с заморозкой телеметрии и продолжение с прежней скорости
    - controller.py: Space включает/выключает паузу; в паузе heartbeat удерживает
    бота нулевой командой (power_stop перезапускается каждые 200 мс), панель не
    перерисовывается, ack копятся в кольце; стрелки в паузе неактивны;
    resume возвращает хранимую команду сразу; реконнект в паузе держит робота стоя
    - OpenSpec: change pause-resum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
2026-10-04 Панель телеметрии: 50 последних ack вместо 20
    - controller.py: TELEMETRY_LINES 20 -> 50. Константа по-прежнему играет
    две роли — глубина кольца TelemetryRing и высота таблицы в render_panel,
    поэтому высота панели выросла с 25 до 55 строк без правок логики рендера
    - OpenSpec: архив change increase-telemetry-rows в
    openspec/changes/archive/2026-10-04-increase-telemetry-rows,
    синк требований «Live telemetry dashboard» и «Панель замораживается во время
    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
2026-10-04 Расшифровка колонок телеметрии над заголовком таблицы
    - controller.py: константа _TABLE_LEGEND (43 и 55 символов, не шире
    таблицы), вставка двух строк в render_panel через crop() — так же,
    как статус и футер, поэтому расшифровка не ест место строки данных и
    не попадает под инверсию. Расшифровка стоит над заголовком и
    отделана от него пустой строкой: в заголовке те же буквы v w mL, что
    и в первой строке рас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
2026-10-18 Первая итерация по исправлению фризов
2026-10-19 Стабилизация скоростей колёс и архивация change'ей
    - EMA-фильтр измеренной скорости (tau=60 мс): std(oL/oR) 8.5/12.1 -> 1.2/1.6, дрожание ШИМ убрано.
    - Исправлен ложный watchdog: (uint32_t)(millis() - lastCommandMs) вместо now - lastCommandMs (переполнение давало stop()/resetPid() раз в несколько секунд).
    - Живой прогон 120/150 мм/с: 0 сбросов ПИД, асимметрия mR-mL +1.3 % / +0.7 % после сходимости интегратора.
    - Архивированы changes decouple-telemetry-from-commands и balance-wheel-sp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
2026-10-19 docs: интент по быстрому выравниванию скоростей колёс
    Отложенная задача: убрать ~15-секундную сходимость асимметрии колёс.
    Замеры на подвесе 120/150 мм/с, гипотеза (постоянный сдвиг ШИМ ~33),
    варианты (Ki / per-wheel FF-трим / проверка энкодера) и решающий тест.
2026-10-19 Удаление рампы разгона (no-op) и синхронизация спеки motion-control
    - Рампа была отключена (RAMP_DURATION_MS = 1) и не давала промежуточных значений: controlLoop() стартует не раньше чем через PID_PERIOD_MS после setTarget(), поэтому t >= 1 сразу.
    - Удалены rampedLinear/rampFrom/rampStartMs/ramping, updateRamp(), RAMP_DURATION_MS; PID и FF работают от targetLinear.
    - Прошивка: 8592 -> 8278 байт flash, 456 -> 430 байт RAM.
    - Живой прогон 120/150 мм/с: 0 сбросов ПИД, ровность и сходимость с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
2026-10-25 Перевод Bluetooth-канала HC-06 на 115200 с автопереводом при старте
    - Прошивка сама переводит HC-06 на 115200 в setup(): ждёт 2.5 с, определяет
    диалект AT (официальный — без перевода строки, установленный клон — только
    `AT\r\n` с `ERROR:(0)` на первую команду), отправляет `AT+BAUD8` с резервом
    `AT+UART=115200,0,0`, проверяет связь на 115200 и перебирает
    19200/38400/57600, если модуль оставлен на промежуточной скорости.
    - Диалект опред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
2026-10-25 Вынос конфигурации HC-06 в отдельный таб bt_config.ino
    - В bt_config.ino перенесены BT_BAUD, весь AT-диалог (определение диалекта,
    AT+BAUD8 с резервом AT+UART=115200,0,0), перебор 19200/38400/57600, коды
    результата и мигание D13.
    - btConfigureModule() сам включает D13 на время последовательности и во всех
    ветках оставляет Hardware Serial на BT_BAUD, поэтому из setup() убраны
    pinMode/digitalWrite для D13 и дублирующий Serial.begin(BT_BAUD).
    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
2026-10-25 Декомпозиция скетча: команды, моторы/PID и телеметрия в отдельных табах
    - motor_controller.ino: 444 -> 54 строки, остались только setup()/loop() и общий
    enum WheelId; константы и состояние разложены по модулям.
    - commands.ino: буфер строки, handleCommand(), commandsProcess(), watchdog,
    счётчик команд и последняя уставка; наружу — commandsProcess(),
    commandsWatchdogTick() и аксессоры для телеметрии.
    - motors.ino: пины, константы, Wheel, энкодеры с ISR(PCINT1_vect), set_speed()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
2026-10-25 Перенос PC-пульта в pc_control и удаление устаревших тестовых скетчей
    - controller.py и connect-to-bt.sh перенесены из папки скетча в
    src/motor_controller/pc_control/ (100% rename, содержимое не менялось).
    - Удалены проверочные скетчи: bt_echo_test (bt_echo_test.ino, echo_test.py) и
    encoder_test.ino. Гипотезы, ради которых они создавались, закрыты; канал и
    энкодеры проверяются боевой прошивкой и её телеметрией.
    - Прошивка не затрагивается: Arduino ком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
2026-10-25 Удаление устаревших требований тестовых скетчей
    - Удалены capability bt-echo-test (6 требований) и encoder-test-sketch
    (4 требования): скетчи bt_echo_test.ino, echo_test.py и encoder_test.ino
    удалены в 15980d3, их гипотезы закрыты боевой прошивкой и телеметрией.
    - encoder-test-sketch перед удалением приведён к валидной структуре
    (## Purpose, ## Requirements): файл начинался с ## ADDED Requirements, из-за
    чего CLI не видел его требования и не мог применить уд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

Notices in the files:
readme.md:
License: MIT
